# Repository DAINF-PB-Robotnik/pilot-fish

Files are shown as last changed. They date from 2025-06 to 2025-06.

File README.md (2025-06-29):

# Pilot Fish



An autonomous Raspberry Pi 4 rover that **follows** a colored object (“fish”) in an aquarium using computer vision with Python, and **avoids** obstacles via 8 ultrasonic sensors on an Arduino Mega.
Movement is commanded through an H-bridge and PWM.

---

## Table of Contents

- [Overview](#overview)  
- [Features](#features)
- [Prerequisites](#prerequisites)  
- [3D Models & Bill of Materials](#3d-models--bill-of-materials)    
- [Installation](#installation)  
- [Configuration](#configuration)  
- [File Structure](#file-structure)  
- [Usage](#usage)  
- [Photo Dataset](#photo-dataset)  
- [Contributing](#contributing)  
- [License](#license)  

---

## Overview

`Pilot_Fish`:

1. Captures frames from Picamera2.  
2. Tracks a colored “fish” via HSV→contour, computes centroid.  
3. Divides view into a 3×3 grid and compensates for any camera rotation with `rotate_index()`.  
4. Reads **8** HC-SR04 sensors over USB (ttyACM0) from an Arduino Mega at 0.2 s intervals.  
5. If the sensor **in the fish’s heading** is below the proximity limit, enters **avoidance**:  
   - Picks the clearest sensor (distance ≥ limit) as the escape direction.  
   - If no direction is clear, **stops** globally.  
6. Otherwise, if the fish’s path is clear, resumes **fish-follow**: grid→Direction mapping.  
7. Renders grid, rotated labels (`rotate_labels()`), contour, centroid and FPS on screen.  
8. Motor control via `Direction.drive()` (Braitenberg) or simple H-bridge commands.

All parameters (pins, HSV, sensor mapping, weights, limits, camera) live in **config.yaml**.

---

## Features

- **Fish-following** in a 3×3 grid, with camera-rotation compensation  
- **Obstacle avoidance** in fish’s heading via best-escape Braitenberg  
- **8-sensor array** on Arduino Mega → serial reader in Python  
- **Dynamic logging** of sensor labels & distances (e.g. `F=12.3 cm | R=45.6 cm`)  
- **Config-driven**: every pin, limit, weight, label and mapping in YAML  
- **Systemd service** for auto-start on boot  

---

## Prerequisites

Before you begin, ensure you have the following hardware and software:

### Hardware

- **Raspberry Pi 4** with camera connector  
- **Picamera v2** (or HQ Camera)  
- **2 × H-bridge drivers** (e.g. L298N)  
- **4 × DC motors** (JGA25-370 DC 12V 100 RPM, ≥ 2 kg·cm torque)  
- **Arduino Mega** (any Mega-series)  
- **8 × HC-SR04 ultrasonic sensors**  
- **Power supply** (12 V for motors, 5 V / 3 A for Pi)  
- **Jumper wires**, mounting hardware, chassis, wheels

### Software

- **Raspberry Pi OS** (Bullseye or newer)  
- **Python 3.7+**  
- System packages:
  - `python3-venv`  
  - `python3-pip`  
  - `python3-opencv`  
- Python libraries (installed via `pip install -r requirements.txt`):
  - `picamera2`  
  - `opencv-python`  
  - `RPi.GPIO`  
  - `pyyaml`  
  - `colorama`  
  - `pyserial`  
- **Git** (to clone this repo)  
- **systemd** (for the `fish.service` unit)  

---

## 3D Models & Bill of Materials

All custom parts live in the [`3D/`](3D/) folder, in both CAD (STEP, FCStd) and mesh (STL) formats.

| Model / Hardware | File / Spec | Description | Qty |
|---|---|---|-----|
| **Chassis Base** | `3D/parts/chassis.stl` | Main chassis platform | 1 |
| **Sensor Bracket** | `3D/parts/sensor_mount.stl` | Ultrasonic sensor mount | 8 |
| **Motor Mount Plate**  | `3D/parts/motor_mount.stl` | DC motor mounting plate | 4 |
| **Full Assembly** | `3D/assemblies/assembly.step` | Complete assembly for CAD import  | 1 |
| **M2.5×6 mm screws** | Stainless steel | Fasten 3D-printed parts | 16  |
| **M2.5 nuts** | Stainless steel | Securing screws | 16  |
| **DC Motors** | JGA25-370 DC 12V 100 RPM, ≥2 kg·cm| Drive wheels | 4 |
| **H-bridge driver** | L298N or equivalent | Motor control via PWM | 2 |
| **Arduino Mega** | Any Mega-series | Reads 8× HC-SR04 via serial | 1 |
| **HC-SR04 sensor** | Ultrasonic distance sensor | Obstacle detection | 8 |

---

## Installation

Follow these steps to install and configure **Pilot-Fish** in either **contour** or **YOLO** mode. All you need is the unified `install.sh` script.

1. **Clone the repository**

   ```bash
   git clone https://github.com/DAINF-PB-Robotnik/pilot-fish.git
   cd pilot-fish
   ```

2. **Make the installer executable**

   ```bash
   chmod +x install.sh
   ```

3. **Run the installer**\
   Choose either **contour** (color-based) or **yolo** (neural-network) mode:

   ```bash
   sudo ./install.sh contour
   ```
   **— OR —**
   ```bash
   sudo ./install.sh yolo
   ```

   This will:

   - Install system packages (Python 3, OpenCV, libcamera-utils, Atlas, HDF5, Qt, etc.)
   - Create a dedicated virtual environment (`.venv_contour` or `.venv_yolo`)
   - Install Python dependencies from `code/<mode>/requirements.txt`
   - Generate and enable a `fish.service` systemd unit to launch your chosen mode on boot

5. **Verify and manage the service**

   - Check status:
     ```bash
     systemctl status fish.service
     ```
   - Watch live logs:
     ```bash
     journalctl -u fish.service -f
     ```
   - Manually stop or start:
     ```bash
     sudo systemctl stop  fish.service
     sudo systemctl start fish.service
     ```

## Quick Installs

### Contour mode:
```bash
git clone https://github.com/DAINF-PB-Robotnik/pilot-fish.git && cd pilot-fish && chmod +x install.sh && sudo ./install.sh contour
```
### YOLO mode:
```bash
git clone https://github.com/DAINF-PB-Robotnik/pilot-fish.git && cd pilot-fish && chmod +x install.sh && sudo ./install.sh yolo
```

---

## Configuration

Edit **`config.yaml`** to adjust parameters for serial, sensors, Braitenberg, control, and camera:

```yaml
# Serial connection to Arduino Mega
serial:
  port:       "/dev/ttyACM0"    # USB serial port
  baudrate:   115200             # Serial baud rate
  timeout_s:  1.0                # Read timeout in seconds

# Ultrasonic sensor polling
sensor_read:
  num_sensors: 8                 # Total HC-SR04 sensors
  interval_s:  0.2               # Poll interval in seconds
  labels:      ["F","FR","R","BR","B","BL","L","FL"]

# Map each 3×3 grid cell to a sensor index
sensor_map:
  - [7, 0, 1]
  - [6, null, 2]
  - [5, 4, 3]

# Braitenberg behavior parameters
braitenberg:
  base_speed:      50            # Base PWM duty for motors (%)
  weights_left:   [ -0.5, -0.3,  0.0,  0.3,  0.5,  0.3,  0.0, -0.3 ]
  weights_right:  [  0.5,  0.3,  0.0, -0.3, -0.5, -0.3,  0.0,  0.3 ]

# Control algorithm parameters
control:
  proximity_limit_cm:     40.0    # Distance threshold to trigger avoid (cm)
  critical_limit_cm:      10.0    # Distance to stop immediately (cm)
  smoothing_alpha:        0.15    # Sensor smoothing factor (0 = instant, 1 = max smoothing)
  hysteresis_cm:          5.0     # Hysteresis margin around the threshold (cm)
  max_acceleration:      100.0    # Max PWM change per second for ramping

# Camera settings
camera:
  rotation:   90                # Physical rotation of camera (0,90,180,270)
  format:     "XRGB8888"       # Libcamera output format
  resolution: [640, 480]        # Frame size (width, height)
  framerate:  30                # Capture FPS

# Logging level
logging:
  level:      "INFO"           # DEBUG, INFO, WARNING, ERROR, CRITICAL
```

After editing, restart the service:

```bash
sudo systemctl restart fish.service
```
---

## File Structure

```
3D/                        # 3D printable parts (Fusion 360 and STL files)
├── F3D/                   # Editable Fusion 360 files
├── STL/                   # Exported STL models for 3D printing

circuit/                  # Schematics and diagrams
├── fish.fzz              # Editable Fritzing project
├── fish.png              # Circuit image

code/
├── contour/              # HSV + contour-based tracking
│   ├── config.py         # YAML parser and utility functions
│   ├── config.yaml       # Configuration for contour mode
│   ├── control.py        # Avoidance and tracking logic
│   ├── direction.py      # Motor control logic
│   ├── draw.py           # Grid and overlay rendering
│   ├── main.py           # Entry point for contour version
│   ├── motor.py          # H-bridge interface
│   ├── pwm.py            # PWM helper class
│   ├── requirements.txt  # Python dependencies
│   ├── sensor.py         # Reads sensors from Arduino
│   ├── track.py          # Contour-based tracking logic
│   └── view_requirements.sh  # Shows installed packages
├── yolo/                 # YOLOv8-based tracking
│   ├── best.pt           # YOLOv8 weights
│   ├── config.py         # YAML parser and utility functions
│   ├── config.yaml       # Configuration for yolo mode
│   ├── control.py        # Avoidance and tracking logic
│   ├── direction.py      # Motor control logic
│   ├── draw.py           # Grid and overlay rendering
│   ├── main.py           # Entry point for yolo version
│   ├── motor.py          # H-bridge interface
│   ├── photo.py          # Dataset photo capture
│   ├── pwm.py            # PWM helper class
│   ├── requirements.txt  # Python dependencies
│   ├── sensor.py         # Reads sensors from Arduino
│   ├── track.py          # YOLOv8-based tracking logic
│   ├── light/            # Light condition photos (omitted)
│   ├── normal/           # Normal condition photos (omitted)
│   └── shake/            # Shaking condition photos (omitted)
├── mega/
│   └── mega.ino          # Arduino sketch for ultrasonic sensors

install.sh                # Unified installer script for contour/yolo
LICENSE                   # MIT License
README.md                 # This documentation
```

---

## Usage

### Interactive

```bash
source .venv/bin/activate
python main.py
```

Open windows **MAIN** (with overlays) and **BINARY** (mask).

### As a Service

```bash
sudo systemctl start fish.service
sudo journalctl -f -u fish.service
```
### Requirements Generation

If you ever need to (re)generate the `requirements.txt` for your chosen mode, run:

```bash
sudo ./install.sh contour generate-requirements
```
**— OR —**
```bash
sudo ./install.sh yolo generate-requirements
```
This will activate any existing venv, dump its `pip freeze` into `code/<mode>/requirements.txt`, and then exit.

---

## Photo Dataset

```bash
python photo.py
```

1. Choose mode: `1` normal, `2` light, `3` shake
2. Enter count and interval
3. Images saved under `./normal/`, `./light/`, or `./shake/`.

---

## Contributing

1. Fork & clone
2. `git checkout -b feat/your-feature`
3. Commit & push
4. Open a Pull Request

---

## License

This project is licensed under the [MIT License](LICENSE).

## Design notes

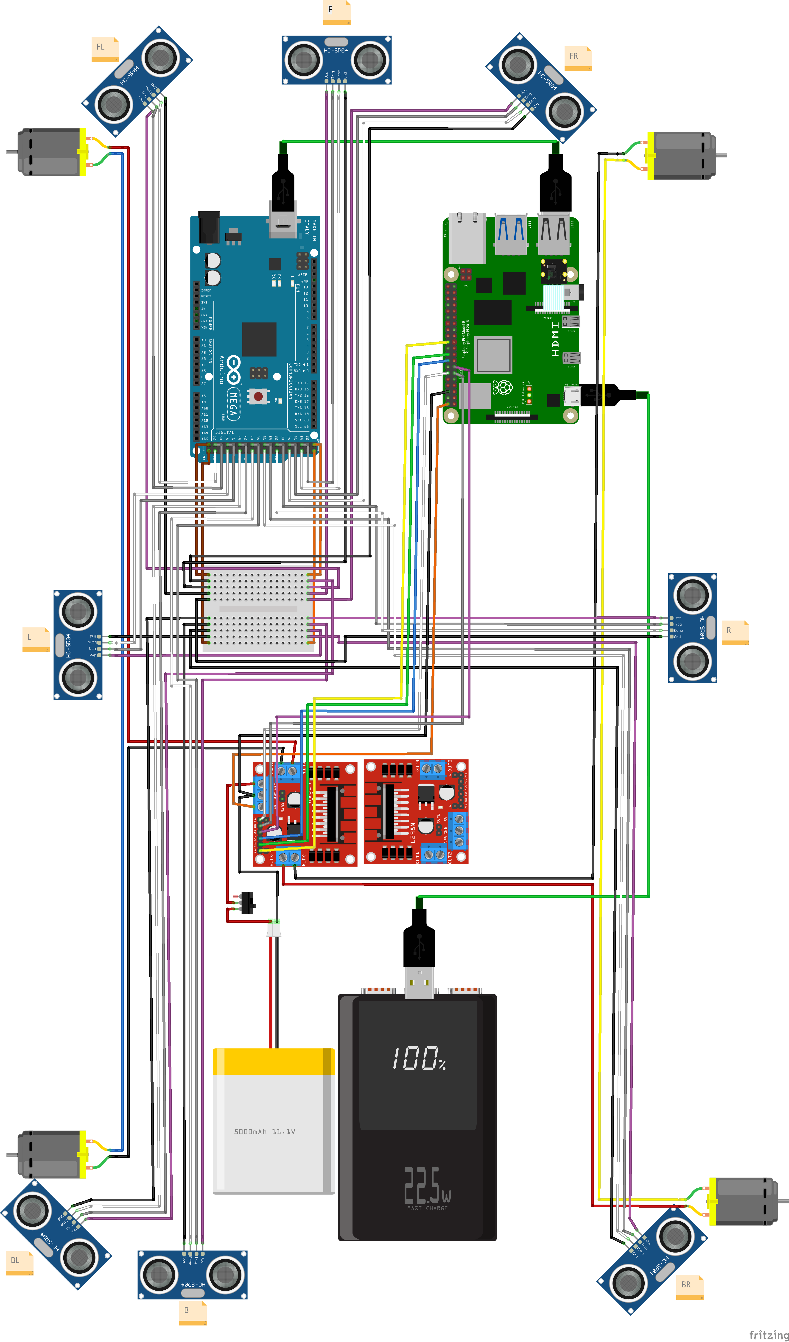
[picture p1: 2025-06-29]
circuit/fish.png

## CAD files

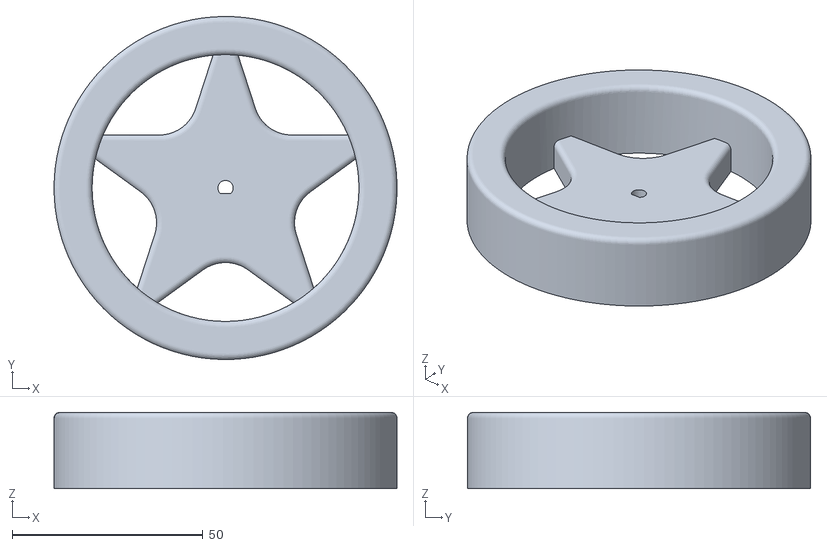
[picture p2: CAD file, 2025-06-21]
3D/STL/wheel.stl
90.0 x 90.0 x 20.0

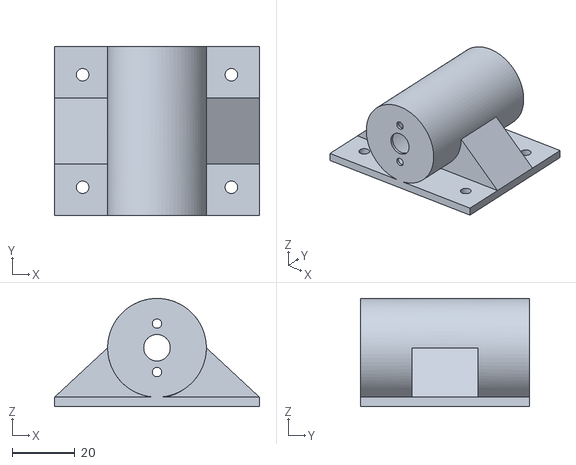
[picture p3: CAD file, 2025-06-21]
3D/STL/motor_support_v6.stl
65.6 x 54.0 x 34.6

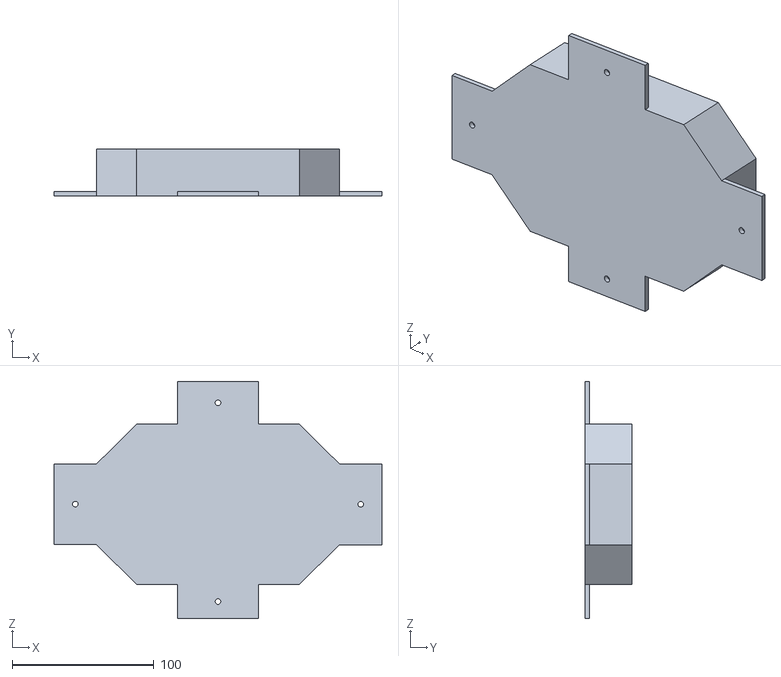
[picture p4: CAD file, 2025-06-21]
3D/STL/aquarium_base.stl
231.0 x 33.0 x 166.9

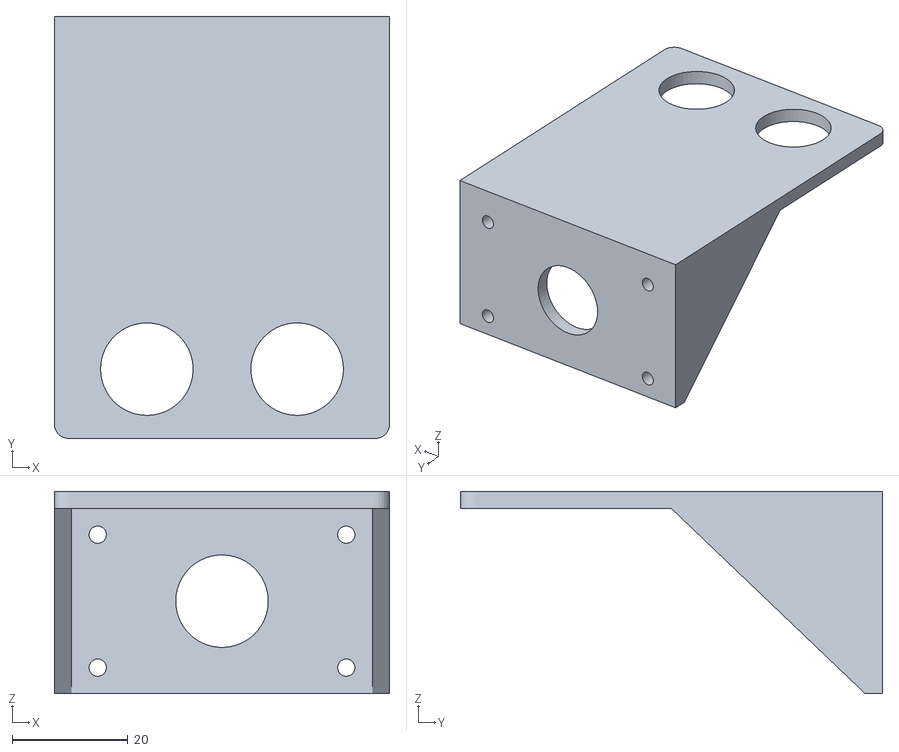
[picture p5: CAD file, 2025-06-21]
3D/STL/hcsr04_support_v4.stl
58.0 x 73.0 x 35.0

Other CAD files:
3D/F3D/aquarium_base.f3d
3D/F3D/hcsr04_support_v4.f3d
3D/F3D/motor_support_v6.f3d
3D/F3D/wheel.f3d

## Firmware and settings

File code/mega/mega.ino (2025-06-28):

/**
 * @file ultrasonic_8_sensor_array.ino
 * @brief Reads 8 HC-SR04 ultrasonic sensors sequentially on an Arduino Mega.
 *
 * This firmware is designed to run on an Arduino Mega 2560. It continuously measures
 * distances from 8 ultrasonic sensors and sends the collected data over USB
 * serial when it receives a specific character ('R') from the host.
 *
 * Communication Protocol:
 * - Host sends: 'R' (char)
 * - Arduino replies: A single line string with 8 distance values (in cm, with
 * one decimal place), separated by semicolons. e.g., "15.2;30.0;Err;..."
 * "Err" indicates a timeout or failed reading for that sensor.
 */
#include <Arduino.h>

//==============================================================================
// SENSOR CONFIGURATION
//==============================================================================

// The total number of ultrasonic sensors connected.
const uint8_t NUM_SENSORS = 8;

// Pin assignments for the HC-SR04 sensors' TRIG and ECHO pins.
// The order here maps to the logical sensor index (0 to 7).
// Sensor 0 -> TRIG=24, ECHO=25
// Sensor 1 -> TRIG=28, ECHO=29
// ...
// Sensor 7 -> TRIG=52, ECHO=53
const uint8_t TRIG_PINS[NUM_SENSORS] = {24, 28, 32, 36, 40, 44, 48, 52};
const uint8_t ECHO_PINS[NUM_SENSORS] = {25, 29, 33, 37, 41, 45, 49, 53};

// Maximum wait time for the echo pulse from a sensor, in microseconds.
// This value determines the maximum measurable distance.
// 12000µs corresponds to a max range of approximately 2 meters.
// (12000µs * 0.0343 cm/µs) / 2 ≈ 205 cm
const unsigned long TIMEOUT_US = 12000UL;

// Buffer to store the latest distance readings for all sensors in millimeters.
// A value of -1 indicates a failed reading (error).
int16_t distances_mm[NUM_SENSORS];


//==============================================================================
// SETUP FUNCTION
//==============================================================================

void setup() {
  // Initialize the serial communication with the host computer.
  Serial.begin(115200);

  // Configure the GPIO pins for all sensors.
  for (uint8_t i = 0; i < NUM_SENSORS; i++) {
    // Set TRIG pins as OUTPUT and ensure they are initially LOW.
    pinMode(TRIG_PINS[i], OUTPUT);
    digitalWrite(TRIG_PINS[i], LOW);
    // Set ECHO pins as INPUT.
    pinMode(ECHO_PINS[i], INPUT);
  }
}


//==============================================================================
// SENSOR MEASUREMENT
//==============================================================================

/**
 * @brief Measures the distance from a single specified sensor.
 * @param idx The index of the sensor to measure (0 to NUM_SENSORS-1).
 * @return The distance in millimeters, or -1 if the reading times out.
 */
int16_t measureSensor(uint8_t idx) {
  // 1) Trigger the sensor by sending a 10µs high pulse on the TRIG pin.
  digitalWrite(TRIG_PINS[idx], LOW);
  delayMicroseconds(2);
  digitalWrite(TRIG_PINS[idx], HIGH);
  delayMicroseconds(10);
  digitalWrite(TRIG_PINS[idx], LOW);

  // 2) Read the duration of the echo pulse. The pulseIn() function waits for the
  //    pin to go HIGH, starts timing, and then waits for the pin to go LOW.
  //    It returns the pulse length in microseconds or 0 if it times out.
  unsigned long duration_us = pulseIn(ECHO_PINS[idx], HIGH, TIMEOUT_US);

  // If duration is 0, it means no echo was received within the timeout period.
  if (duration_us == 0) {
    return -1; // Return -1 to indicate an error.
  }

  // 3) Convert the pulse duration to distance in millimeters.
  //    Formula: distance = (duration / 2) * speed_of_sound
  //    Speed of sound ≈ 0.343 mm/µs
  //    To avoid floating-point math, we use integer arithmetic:
  //    (duration_us * 343) / 2000
  return (duration_us * 343UL) / 2000;
}


//==============================================================================
// MAIN LOOP
//==============================================================================

void loop() {
  // Continuously measure all sensors in sequence and update the global buffer.
  // This ensures that when the host requests data, the latest values are ready.
  for (uint8_t i = 0; i < NUM_SENSORS; i++) {
    distances_mm[i] = measureSensor(i);
    // Optional: a small delay can improve stability for some sensor models,
    // allowing any residual echoes to dissipate.
    // delay(5);
  }

  // Check if the host has sent any data over USB.
  if (Serial.available()) {
    // If the received character is 'R', send back the distance data.
    if (Serial.read() == 'R') {
      for (uint8_t i = 0; i < NUM_SENSORS; i++) {
        // Add a semicolon separator before each value except the first one.
        if (i > 0) {
          Serial.print(';');
        }
        
        int16_t mm = distances_mm[i];
        if (mm < 0) {
          // If the distance is -1, print "Err" to indicate a sensor error.
          Serial.print("Err");
        } else {
          // Send the distance formatted as centimeters with one decimal place.
          // Example: 152mm becomes "15.2"
          Serial.print(mm / 10);      // Integer part in cm (e.g., 152 / 10 = 15)
          Serial.print('.');
          Serial.print(abs(mm % 10));  // Decimal part (e.g., 152 % 10 = 2)
        }
      }
      // Terminate the message with a newline character.
      Serial.println();
    }

    // Clear any other characters from the serial receive buffer to prevent
    // processing old requests.
    while (Serial.available()) {
      Serial.read();
    }
  }
}

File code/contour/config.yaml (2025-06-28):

# config.yaml

# Motor driver pins
motor:
  left_pins: [17, 27]
  right_pins: [23, 24]
  pwm_pins: [18, 25]

# Tracker settings
tracker:
  hsv_lower: [90, 50, 50]
  hsv_upper: [130, 255, 255]
  kernel_size: [5, 5]

# Draw settings
draw:
  grid_color: [0, 255, 0]
  text_color: [0, 0, 0]
  fps_color: [0, 0, 0]
  font_scale: 0.7
  thickness: 2
  quadrant_labels:
    - ["Up-Left", "Up", "Up-Right"]
    - ["Left", "Center", "Right"]
    - ["Down-Left", "Down", "Down-Right"]

control:
  proximity_limit_cm:       40.0    # cm at which we consider “blocked”
  sensor_smoothing_alpha:    0.5    # 0 = raw instant, 1 = fully smoothed
  centroid_smoothing_alpha:  0.15   # for fish‐centroid smoothing
  state_debounce_s:          0.3    # min seconds between state changes
  clear_threshold:           3      # AVOID cycles before returning to FOLLOW
  critical_distance_cm:     20.0    # cm for immediate hard‐stop→AVOID

  # new parameters for minimal AVOID duration
  avoid_min_time_s:         2.0     # seconds to stay in AVOID before allowing FOLLOW

  # dynamic sensor‐read interval bounds
  base_sensor_interval_s:   0.20   # “normal” read interval (s)
  min_sensor_interval_s:    0.05   # fastest interval when very close




# Camera settings
camera:
  rotation: 90
  format: "XRGB8888"
  resolution: [640, 480]
  framerate: 30

# Logging level
logging:
  level: "INFO"

# Serial port for Arduino Mega
serial:
  port: "/dev/ttyACM0"
  baudrate: 115200
  timeout_s: 1.0

# Sensor polling
sensor_read:
  num_sensors: 8
  interval_s: 0.2
  labels: ["F","FR","R","BR","B","BL","L","FL"]

# Sensor map
sensor_map:
  - [7, 0, 1]
  - [6, null, 2]
  - [5, 4, 3]

# Braitenberg parameters
braitenberg:
  base_speed: 50.0
  weights_left: [ -0.5, -0.3, 0.0, 0.3, 0.5, 0.3, 0.0, -0.3 ]
  weights_right: [ 0.5, 0.3, 0.0, -0.3, -0.5, -0.3, 0.0, 0.3 ]

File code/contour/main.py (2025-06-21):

import logging
import cv2
import RPi.GPIO as GPIO
import time

from picamera2 import Picamera2

from config    import setup_logging, CAMERA_FORMAT, CAMERA_RESOLUTION, CAMERA_FRAMERATE
from track     import Track
from draw      import Draw
from control   import Control
from direction import Direction

class Main:
    def __init__(self):
        setup_logging()
        logging.info("Initialization successful.")

        self.tracker    = Track()
        self.control = Control()
        self.drawer     = Draw()

        # Configure & start camera entirely from config
        self.camera = Picamera2()
        self.camera.configure(
            self.camera.create_preview_configuration(
                main     = {"format": CAMERA_FORMAT, "size": CAMERA_RESOLUTION},
                controls = {"FrameRate": CAMERA_FRAMERATE}
            )
        )
        self.camera.start()
        logging.info("Camera started")
        '''
             #comeca
    
    picamv2= Picamera2()
    picamv2.configure(picamv2.create_video_configuration())
    picamv2.start()
    time.sleep(2)
    fourcc = cv2.VideoWriter_fourcc(*'XVID')
    out = cv2.VideoWriter('output.avi',fourcc,20,(640,480))
    start = time.time()
           
    print("gravando")
    while time.time() - start < 180:
        frame = picamv2.capture_array()
        frame = cv2.resize(frame, (640,480))
        out.write(frame)
                 
    out.release()
    picamv2.stop()
    print("Video salvo")
             
            #termina
'''
    def run(self):
        while True:
            frame = self.camera.capture_array()
            
            # 1) FPS tracking moved into Track
            inst_fps, _ = self.tracker.track_fps()

            # 2) Detection + movement
            contour, mask = self.tracker.track_frame(frame)
            self.control.move(frame, contour)

            # 3) Draw overlays (instantaneous FPS only)
            out, bin_mask = self.drawer.render(frame, contour, mask, inst_fps)

            # 4) Display
            #cv2.imshow("BINARY", bin_mask)
            cv2.imshow("MAIN",   out)
            if cv2.waitKey(1) != -1:
                break
                
       
        self.camera.stop()
        cv2.destroyAllWindows()
        GPIO.cleanup()
        

if __name__ == "__main__":
    Main().run()

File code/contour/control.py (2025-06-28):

# control.py

import time
import logging

from sensor    import Sensor
from track     import Track
from direction import Direction
from config    import (
    PROXIMITY_LIMIT,
    SENSOR_NUM,
    SENSOR_LABELS,
    SENSOR_SMOOTHING_ALPHA,
    CENTROID_SMOOTHING_ALPHA,
    CRITICAL_DISTANCE,
    STATE_DEBOUNCE_INTERVAL,
    CLEAR_THRESHOLD,
    BASE_SENSOR_INTERVAL,
    MIN_SENSOR_INTERVAL,
    AVOID_MIN_TIME,
    rotate_index,
    SENSOR_MAP,
)

class Control:
    """
    - 3-sensor groups per heading (CRITICAL_GUARDS).
    - Dynamic read interval ∈ [MIN, BASE], but MIN when in AVOID.
    - Follow-speed ∈ [0–100%] ∝ min(group_distance)/PROXIMITY_LIMIT.
    - Hard-stop → AVOID if any group sensor ≤ CRITICAL_DISTANCE.
    - Center cell (1,1) → only stop (no AVOID) until fish moves.
    - Remain in AVOID ≥ AVOID_MIN_TIME before FOLLOW.
    - Debounced FOLLOW⇄AVOID via STATE_DEBOUNCE_INTERVAL & CLEAR_THRESHOLD.
    - Centroid smoothing via CENTROID_SMOOTHING_ALPHA.
    """

    CRITICAL_GUARDS = {
        (0,1): [0,1,7], (1,0): [6,5,7],
        (1,2): [2,1,3], (2,1): [4,3,5],
        (0,0): [7,0,6], (0,2): [1,0,2],
        (2,0): [5,4,6], (2,2): [3,4,2],
    }
    DIAG_FALLBACKS = {
        (0,0): [(2,2),(0,1),(1,0)],
        (0,2): [(2,0),(0,1),(1,2)],
        (2,0): [(0,2),(2,1),(1,0)],
        (2,2): [(0,0),(2,1),(1,2)],
    }

    def __init__(self):
        self.sensor            = Sensor()
        self.limit             = PROXIMITY_LIMIT

        # sensor‐read timing
        self._read_interval    = BASE_SENSOR_INTERVAL
        self._last_read_time   = 0.0

        # logging helper
        self._last_action_msg  = None

        # smoothing buffers
        self._sensor_smoothed  = None
        self._cx, self._cy     = None, None

        # Finite State Machine
        self.state             = 'FOLLOW'
        self._state_time       = 0.0
        self._clear_count      = 0

    def move(self, frame, contour):
        now = time.time()

        # 1) Fish detection → raw heading cell
        if contour is None:
            self._enter_avoid(now)
            Direction.stop()
            return self._log("[BRAITE] No contour")

        x, y = Track.contour_center(contour)
        if x is None or y is None:
            self._enter_avoid(now)
            Direction.stop()
            return self._log("[BRAITE] Centroid failed")

        h, w     = frame.shape[:2]
        raw_r    = max(0, min(2, int(y / (h/3))))
        raw_c    = max(0, min(2, int(x / (w/3))))
        raw_cell = rotate_index(raw_r, raw_c)

        # 1a) Center-cell override: stop only
        if raw_cell == (1,1):
            Direction.stop()
            return self._log("[FISH] Center stop")

        # 2) Compute ratio from heading group
        idxs      = Control.CRITICAL_GUARDS.get(raw_cell, [])
        dists     = self._sensor_smoothed or [self.limit]*SENSOR_NUM
        group_min = min(dists[i] for i in idxs) if idxs else self.limit
        ratio     = max(0.0, min(1.0, group_min / self.limit))

        # 2a) Override interval when in AVOID
        if self.state == 'AVOID':
            self._read_interval = MIN_SENSOR_INTERVAL
        else:
            self._read_interval = max(
                MIN_SENSOR_INTERVAL,
                BASE_SENSOR_INTERVAL * ratio
            )

        # 3) Read & smooth sensors when due
        if now - self._last_read_time >= self._read_interval:
            raw_vals = self.sensor.get()
            self._last_read_time = now

            if self._sensor_smoothed is None:
                # first time: Err→inf, else raw
                self._sensor_smoothed = [
                    float('inf') if d < 0 else d
                    for d in raw_vals
                ]
            else:
                αs = SENSOR_SMOOTHING_ALPHA
                for i, d in enumerate(raw_vals):
                    if d < 0:
                        # keep previous value
                        continue
                    prev = self._sensor_smoothed[i]
                    if prev == float('inf'):
                        # first valid after inf → instant replace
                        self._sensor_smoothed[i] = d
                    else:
                        # normal exponential smoothing
                        self._sensor_smoothed[i] = prev*αs + d*(1-αs)

            logging.info(" | ".join(
                f"{lab}={dist:.1f}cm"
                for lab, dist in zip(SENSOR_LABELS, self._sensor_smoothed)
            ))

        dists = self._sensor_smoothed or [float('inf')]*SENSOR_NUM

        # 4) Hard-stop → enter AVOID if any critical sensor ≤ CRITICAL_DISTANCE
        if any(dists[i] <= CRITICAL_DISTANCE for i in idxs):
            self._enter_avoid(now)

        # 5) Global stop if all directions blocked
        if all(d < self.limit for d in dists):
            self._enter_avoid(now)
            Direction.stop()
            return self._log("[BRAITE] All blocked")

        # 6) Debounce FOLLOW⇄AVOID + enforce minimal AVOID time
        elapsed = now - self._state_time
        primary = SENSOR_MAP[raw_cell[0]][raw_cell[1]]
        if elapsed >= STATE_DEBOUNCE_INTERVAL:
            if self.state == 'FOLLOW':
                if primary is not None and dists[primary] < self.limit:
                    self._enter_avoid(now)
            else:
                if primary is not None and dists[primary] >= self.limit:
                    self._clear_count += 1
                else:
                    self._clear_count = 0

                if (self._clear_count >= CLEAR_THRESHOLD and
                    now - self._state_time >= AVOID_MIN_TIME):
                    self.state       = 'FOLLOW'
                    self._state_time = now

        # 7) Centroid smoothing for FOLLOW movement
        αc = CENTROID_SMOOTHING_ALPHA
        if self._cx is None:
            self._cx, self._cy = x, y
        else:
            self._cx = self._cx*αc + x*(1-αc)
            self._cy = self._cy*αc + y*(1-αc)

        sm_r = max(0, min(2, int(self._cy / (h/3))))
        sm_c = max(0, min(2, int(self._cx / (w/3))))
        smooth_cell = rotate_index(sm_r, sm_c)
        follow_speed = int(ratio * 100)

        # 8) Execute movement
        ACTIONS = {
            (0,0): Direction.up_left,   (0,1): Direction.forward,  (0,2): Direction.up_right,
            (1,0): Direction.left,      (1,1): Direction.stop,     (1,2): Direction.right,
            (2,0): Direction.down_left, (2,1): Direction.back,     (2,2): Direction.down_right,
        }
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

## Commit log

2025-06-21 3D parts
    [alternative_hcsr04_support.stl, aquarium_base.f3d, aquarium_base.stl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]
2025-06-21 hardware diagram
    [fish.fzz]
2025-06-22 att circuit
    [fish.fzz]
2025-06-22 rename circuit png/att circuit fzz
    [fish.fzz]
2025-06-28 paths rewriting, remove alternative sensor support
    [alternative_hcsr04_support.stl]
